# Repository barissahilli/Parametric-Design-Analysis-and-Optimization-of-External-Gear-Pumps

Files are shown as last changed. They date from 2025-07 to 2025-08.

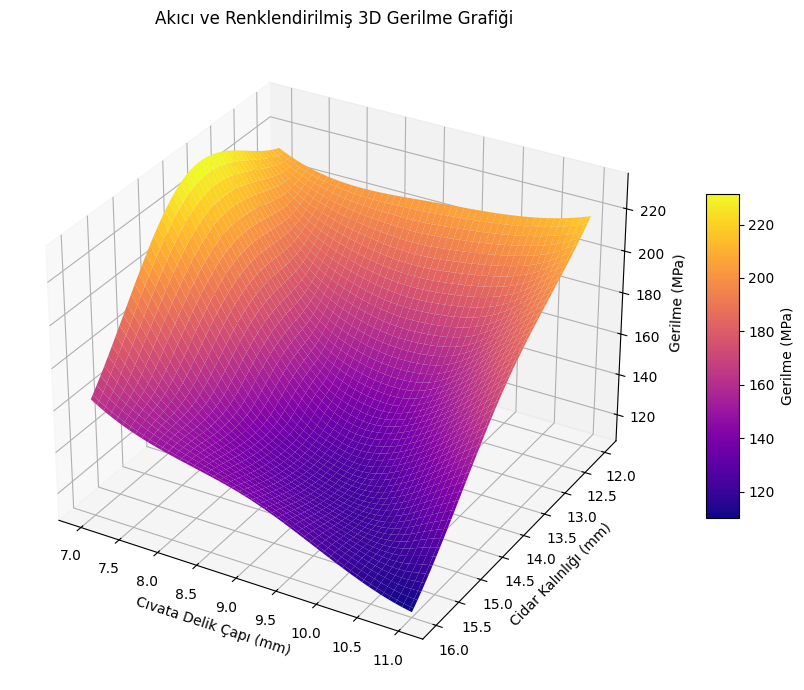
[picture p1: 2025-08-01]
delikcidargerilme.png

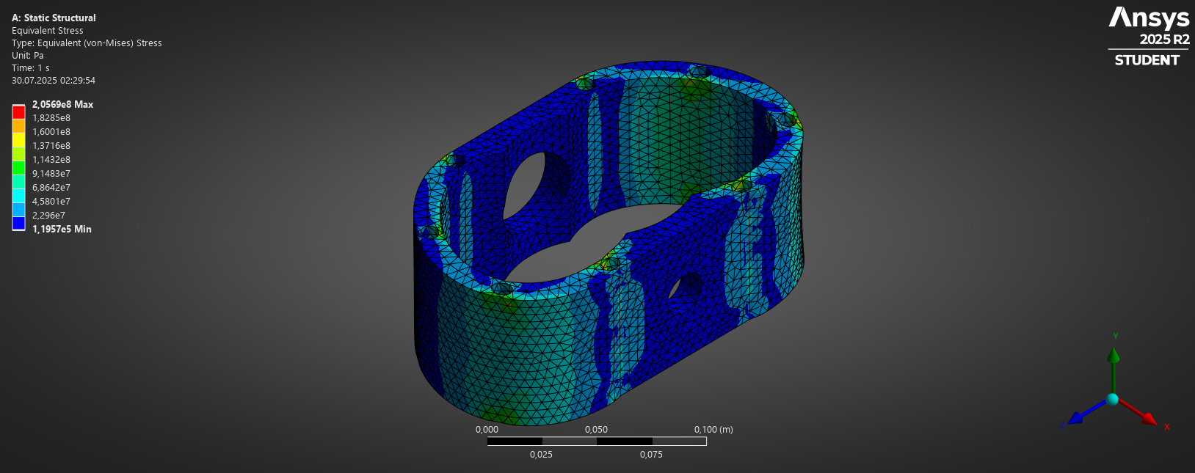
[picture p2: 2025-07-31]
StaticFigure66.png

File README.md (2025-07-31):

# Parametric Design and GDO Analysis of Gear Pump

This project involves the parametric design of a gear pump housing, modeled in SolidWorks and structurally analyzed using ANSYS.

## 📌 Project Overview

- Created 9 different design variations.  
- Analyzed parameters including weight, maximum stress, and maximum displacement.  
- Applied Goal Driven Optimization (GDO) to identify the optimal design.

## 🧪 Tools Used

- SolidWorks (modeling)  
- ANSYS Student (analysis)  
- Excel (DOE table and result analysis)

## 📁 Contents

| File | Description |
|---|---|
| bitirme_raporu.pdf | Detailed project report |
| gdo_grafikleri.png | Stress, weight, and displacement graphs |

## ⚠ Notes

- SolidWorks and ANSYS files are not included. All sections and analysis details are provided in the report.  
- The project was entirely completed using student versions of the software.
- 
> 📄 Note: The final report (bitirme_raporu.pdf) is written in Turkish, as this project was conducted as part of a university graduation requirement in Türkiye.

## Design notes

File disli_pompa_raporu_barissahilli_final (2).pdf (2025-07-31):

T.C.

Dokuz Eylül Üniversitesi

Mühendislik Fakültesi Makine Mühendisliği Bölümü

## DÜZ DİŞLİ POMPANIN PARAMETRİK TASARIMI VE YAPISAL ANALİZİNİN RAPORLANMASI

## HAZIRLAYAN

2021508043 – Barış SAHİLLİ

Temmuz, 2025
İZMİR

## İÇİNDEKİLER

## ÖZET

Bu çalışmada, dişli pompanın parametrik modellemesi SolidWorks yazılımı kullanılarak

yapılmıştır. Oluşturulan model ANSYS Workbench ortamına aktarılmış ve çeşitli analizler

gerçekleştirilmiştir. Yapısal analiz kapsamında von Mises eşdeğer gerilmeler, asal gerilmeler,

deformasyon ve güvenlik katsayıları değerlendirilmiştir. Sonuç olarak, dişli pompa sistemlerinin

dijital ortamda modellenmesi ve simülasyonu ile önceden performans tahmini yapılmasının

önemi ortaya konmuştur.

Anahtar kelimeler: parametrik tasarım, düz dişli pompa, montaj ilişkileri, yapısal analiz.

## 1. GİRİŞ

Dişli pompalar, endüstride sıvı transferinde yaygın olarak kullanılan pozitif deplasmanlı

pompalardır. Bu çalışmada, dişli pompa geometrisinin parametrik olarak modellenmesi ve analiz

edilmesi amaçlanmıştır. Modelleme işlemi SolidWorks yazılımında gerçekleştirilmiş, ardından

analizler ANSYS Workbench ortamında yapılmıştır. Bu sayede tasarımın hem geometrik hem de

yapısal açıdan değerlendirilmesi sağlanmıştır.

## 2. PARAMETRİK MODELLEME (SOLIDWORKS)

SolidWorks yazılımında oluşturulan dişli pompa modeli tamamen parametrik bir yapıda

tasarlanmıştır. Modelde kullanılan tüm ölçüler Global Variables sekmesi ile kontrol

edilebilmektedir. Diş sayısı, modül, merkez mesafesi gibi değişkenler tanımlanarak, bu değerlere

bağlı olarak hem dişli hem de gövde geometrisi otomatik olarak yeniden şekillenmektedir.

Kullanılan başlıca parametrik değişkenler şunlardır:

- Modül (m): Diş yüksekliği, diş profili ve dış çap bu parametreye bağlıdır.
- Diş Sayısı (z): Dişli çapını ve merkez mesafesini belirler. Çap = m × z
- Merkez Mesafesi (a): a = m × z / 2
- Diş Genişliği (b): Dişlinin kalınlığıdır, tork taşıma kapasitesine etki eder.
- Cidar Kalınlığı (t): Gövdeyi saran duvar kalınlığıdır.
- Basma Açısı (alfa): Evolvent diş profili bu açıyla tanımlanır.
- Diş Dibi Çapı (df): df = m * z - 2.5 * m
- Diş Tepesi Çapı (dk): dk = m * z + 2 * m

Montaj sırasında, dişliler eksenel olarak hizalanmış ve uygun hareket kısıtlamaları

tanımlanmıştır. Bu yapı sayesinde, modül ve diş sayısı gibi değişkenlerin değiştirilmesiyle tüm

pompa modeli otomatik olarak güncellenebilmektedir.

## 3. GÖRSEL DETAYLAR VE MONTAJ

Şekil 3.1 – Dişli profiline ait parametrik modelleme detayları

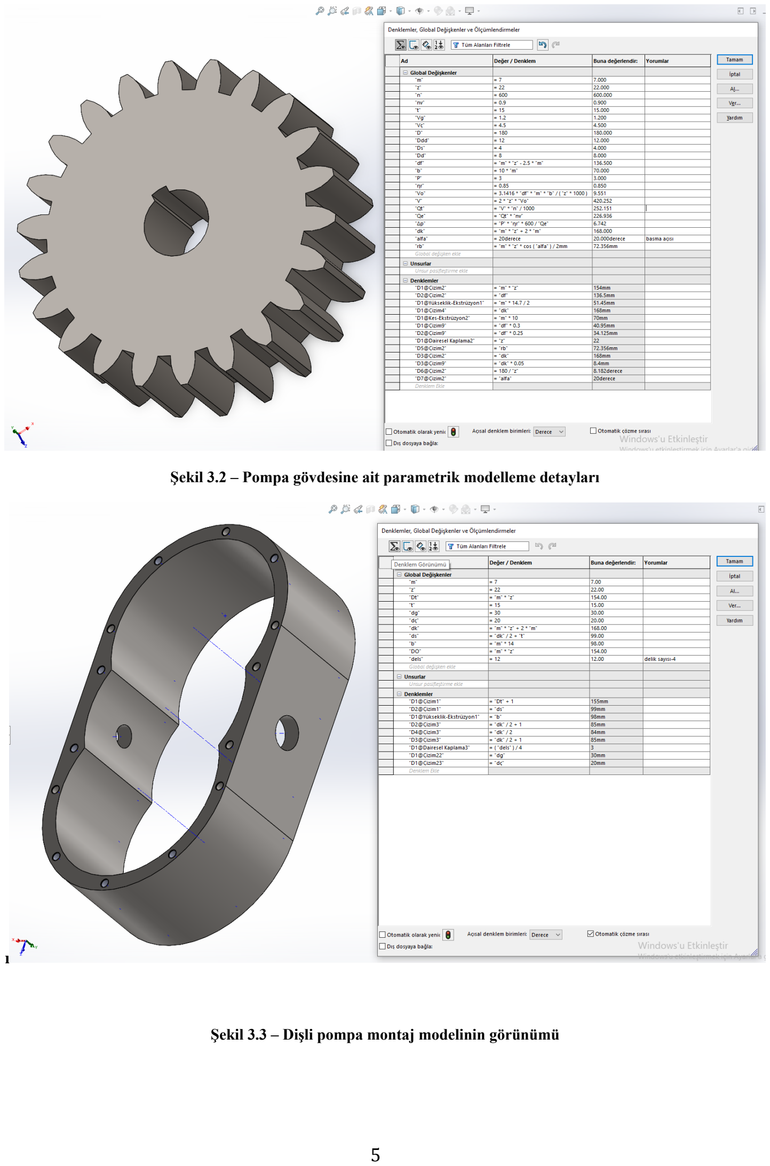
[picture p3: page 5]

Şekil 3.2 – Pompa gövdesine ait parametrik modelleme detayları

ı

Şekil 3.3 – Dişli pompa montaj modelinin görünümü

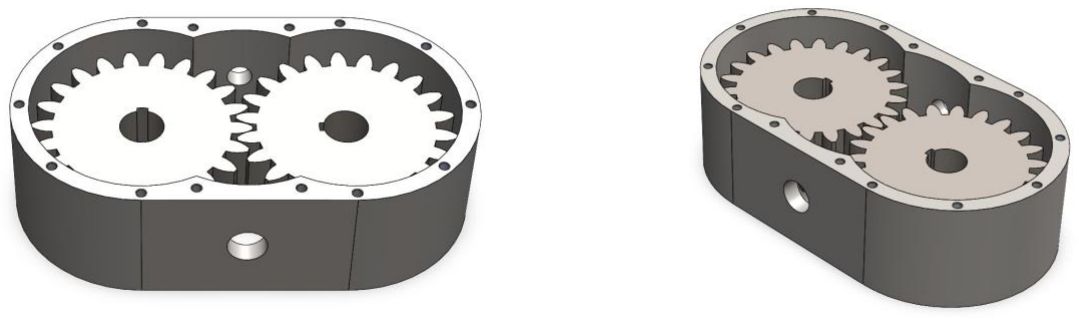
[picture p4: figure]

Şekil 3.4 – Dişli Pompa Çalışma Videosu (QR kod ile izlenebilir)

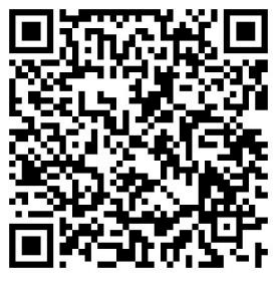
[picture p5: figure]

Alternatif bağlantı: Dişli pompanın çalışma videosunu buraya tıklaayarak izleyebilirsiniz (https://drive.google.com/file/d/1kjITw9gz6Is4c7rqxvNHRtaKOAkZPMQB/view?usp=drive_link)

### 3.1. DIŞLI POMPA MONTAJINDA SOLIDWORKS İLIŞKILERI

Montaj işlemleri sırasında SolidWorks’ün mekanik ilişkiler (mates) sistemi kullanılarak dişli

pompanın parçaları birbirine konumlandırılmış ve doğru hareket ilişkileri tanımlanmıştır.

Aşağıda kullanılan başlıca montaj ilişkileri ve işlevleri açıklanmıştır:

1. Coincident (Çakışık) İlişkisi: Bu ilişki, iki düzlemin veya kenarın aynı hizaya getirilmesini

sağlar.

Kullanım: Pompa gövdesine dişlilerin yataklandığı yüzeylerin hizalanmasında kullanılanılabilir

2. Concentric (Eşmerkezli) İlişkisi: İki silindirik yüzeyin ortak eksen etrafında hizalanmasını

sağlar.

Kullanım: Dişli ile mil, mil ile rulman, rulman ile gövde gibi dönel parçaların aynı eksen

üzerinde düzgün çalışması için uygulanmıştır.

3. Distance (Mesafe) İlişkisi: İki yüzey arasında sabit bir mesafe tanımlar.

Kullanım: Dişli çark ile pompa gövdesi arasındaki boşluk (boşta dönme payı) bu ilişki ile

ayarlanılabilir, montajda aks mesafesi ile ayarlanmıştır.

4. Gear Mate (Dişli İlişkisi): İki dönel parçanın, belirli bir dişli oranına göre senkronize şekilde

dönmesini sağlar, Dişli pompa sisteminde kullanılan ana tahrik dişlisi ile hareketi aktaran dişli

arasında gear mate tanımlanmıştır

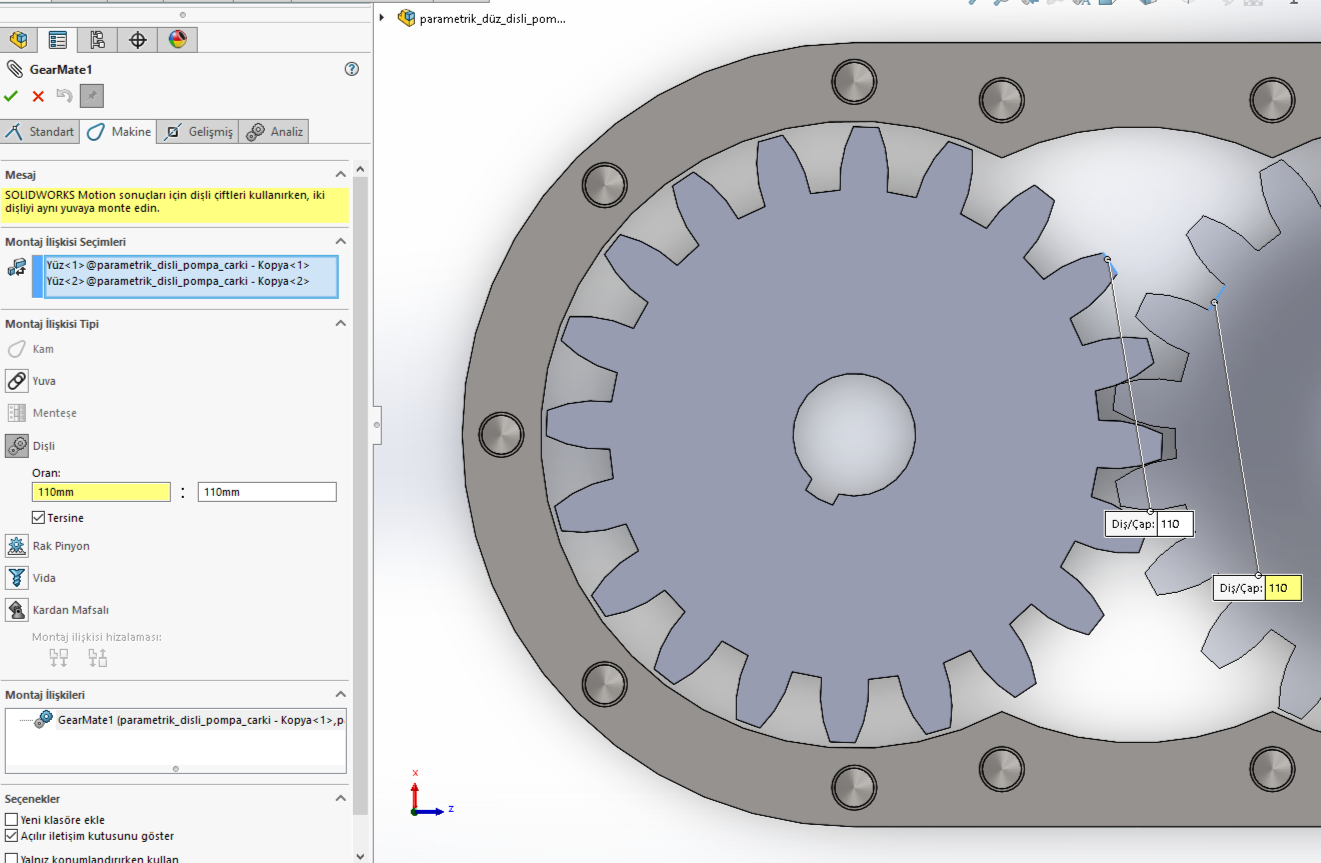
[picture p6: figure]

Şekil 3.5 – Gear Mate İlişkisi Tanımı (SolidWorks)

### 5. Fix (Sabit) İlişkisi Bir parçanın montajda sabit kalmasını sağlar; konumunun değişmesi

engellenir.

Kullanım: Pompa gövdesi montajın referansı olarak sabitlenmiş ve diğer parçalar bu referansa

göre hizalanmıştır.

### 3.2 MALZEME ATAMASI

Bu çalışmada pompa gövdesi ve dişli çarklar için farklı mekanik gereksinimlere uygun olarak

farklı malzemeler seçilmiştir. Pompa gövdesi, genellikle yapısal taşıyıcılığı ön planda olan ve

statik yükler altında çalışan bir bileşen olduğundan, AISI 1020 çelik malzemesi tercih edilmiştir.

AISI 1020 düşük karbonlu bir çelik olup, iyi kaynaklanabilirlik, işlenebilirlik ve maliyet avantajı

sunar. Ayrıca yüzey sertleştirme işlemleriyle dayanımı artırılabilir. Düşük karmaşıklıktaki

geometriler ve dar tolerans gerektirmeyen bölgeler için yeterli mekanik özelliklere sahiptir.

Dişli çarklar ise dönel hareketin ve yüksek temas gerilmelerinin oluştuğu elemanlar olduğundan,

daha yüksek mukavemet, tokluk ve aşınma dayanımı gerektirir. Bu nedenle dişliler için AISI

4130 alaşımlı çelik tercih edilmiştir. AISI 4130, yüksek mukavemetli, ısıl işlemle

sertleştirilebilen bir çeliktir. Bu çalışmada, 870 °C’de tavlanmış hali esas alınarak kullanılmıştır.

Bu ısıl işlem, çeliğin çekme ve akma dayanımını artırırken, malzemenin darbeye karşı dayanıklı

kalmasını sağlar. Böylece dişlilerin sürekli çalışan bir pompa sisteminde güvenli ve uzun ömürlü

performans göstermesi sağlanır.

Malzeme seçimi yapılırken, parçaların yük tipi, hareket durumu, işlenebilirlik, maliyet ve üretim

kolaylığı gibi kriterler dikkate alınmıştır. Seçilen malzemeler, ANSYS ortamında yapılan yapısal

analizlerde de dikkate alınarak modele atanmıştır.

### 3.3 ÇALIŞMA PRENSİBİ

Pozitif deplasmanlı düz dişli pompalar, iki adet birbirine kenetlenmiş düz dişli çarkın dönmesiyle

çalışan hacimsel pompalardır. Pompa çalıştığında, tahrik miline bağlı olan bir dişli çark hareket

eder ve bu hareket diğer çarkı da döndürür. Dişliler dönmeye başladığında, giriş tarafında dişler

arasındaki boşluklar genişler ve bu bölgedeki hacim artışı sayesinde akışkan içeri çekilir.

Akışkan, dişlilerin çevresel hareketi ile gövde iç yüzeyinden çıkış tarafına taşınır. Bu sırada

dişlilerin temasta olduğu orta bölgede sızdırmazlık sağlandığı için sıvı tekrar girişe dönemez.

Dişliler çıkış tarafında birbirine yaklaşırken, aralarındaki hacim azalır ve akışkan sistem dışına

doğru basılır. Bu mekanizma sayesinde pompa, sabit hacimli akışkan transferi sağlar ve yüksek basınç altında verimli çalışabilir. Yapısı gereği, bu tür pompalar düşük debili ama yüksek

basınçlı sistemlerde tercih edilir

Dişli çarkların dönme yönü sayesinde sıvı, emişten çıkışa doğru düzgün bir şekilde yönlendirilir.

Bu pompalarda debi; diş sayısı, modül, diş genişliği, devir sayısı gibi parametrelerle doğrudan

ilişkilidir. Bu nedenle pompalar, istenilen akış şartlarına göre parametrik olarak

boyutlandırılabilir. Bu çalışmada geliştirilen modelde de tasarım değişkenleri SolidWorks

ortamında parametrik hale getirilmiş, böylece farklı senaryolara uygun pompa geometrileri

kolayca elde edilebilir hale gelmiştir.,

Pozitif deplasmanlı pompalar, merkezkaç pompalara kıyasla sabit debi sağladıkları için hidrolik

sistemlerde sıkça tercih edilmektedir

### 3.4 PARAMETRİK MODELİN VERİ GİRİŞLERİ VE HESAPLAMALAR

Bu çalışmada, dişli tip pozitif deplasmanlı bir pompa gövdesinin gerilme analizi ve tasarım

optimizasyonu amacıyla parametrik modelleme yöntemi uygulanmıştır. SolidWorks ortamında

oluşturulan model, Ansys Workbench ile entegre edilerek sonlu elemanlar analizine uygun hale

getirilmiştir. Modellemede 12 adet fiziksel ve geometrik parametre tanımlanmıştır. Bu

parametreler arasında cidar kalınlığı (t), modül (m), diş sayısı (z), devir sayısı (n), volümetrik

verimlilik (ηv), efektif debi (Qe), akışkanın giriş ve çıkış hızları (Vg, Vç), gövde üzerindeki açı

ve delik ölçüleri (D, Dd, Ddd, Ds) gibi tasarımı doğrudan etkileyen değerler yer almaktadır.

Tanımlanan bu parametreler doğrultusunda toplam 7 temel formül kullanılarak çıkış debisi (QT),

teorik debi, pompa çıkış gücü (P), basınç farkı (Δp), giriş/çıkış delik çapları (di, do) gibi çıktılar

hesaplanmıştır. Böylece tasarıma girilen her bir parametre değişikliğinde tüm ilişkili boyutlar ve

performans değerleri otomatik olarak güncellenmekte, hem modelin doğruluğu hem de

analizdeki hassasiyet korunmaktadır. Bu yaklaşım, pompa gövdesinin fiziksel koşullar altında

vereceği tepkilerin daha doğru analiz edilmesini sağladığı gibi, olası tasarım hatalarının önüne geçilmesinde de büyük avantaj sunmaktadır. Örnek modellemede kullanılan veri girişleri ve

hesaplamalar şekil 3.6 ve şekil 3.7 üzerinde gösterilmiştir.

Şekil 3.6

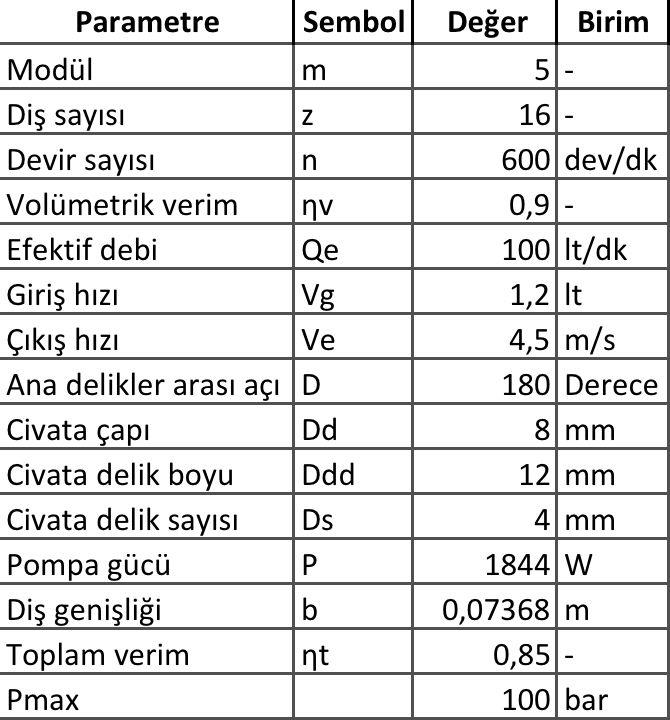
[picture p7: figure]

Bu çalışmada, maksimum çıkış basıncı (Pmax) 100 bar ve toplam verimlilik 0,85 olarak kabul

edilmiştir. Diğer parametreler bu kabuller doğrultusunda düzenlenmiş ve hesaplamalarda

referans alınmıştır.

Basınç farkı (Δp), akışkanın su olduğu varsayımı ile Bernoulli prensibine dayalı olarak, giriş ve

çıkış hızları (Vg ve Vζ) dikkate alınarak hesaplanmıştır. Diş genişliği “b” değeri, birim

dönüşümleri göz önünde bulundurularak milimetre (mm) yerine metre (m) cinsinden girilmiş ve

hesaplamalar buna göre uyarlanmıştır. Pompa çıkış gücü (P), Şekil 3.7’de verilen teorik formüllerden türetilerek elde edilmiş, tüm değerler parametrik modellemede referans alınarak

SolidWorks ortamına entegre edilmiştir.

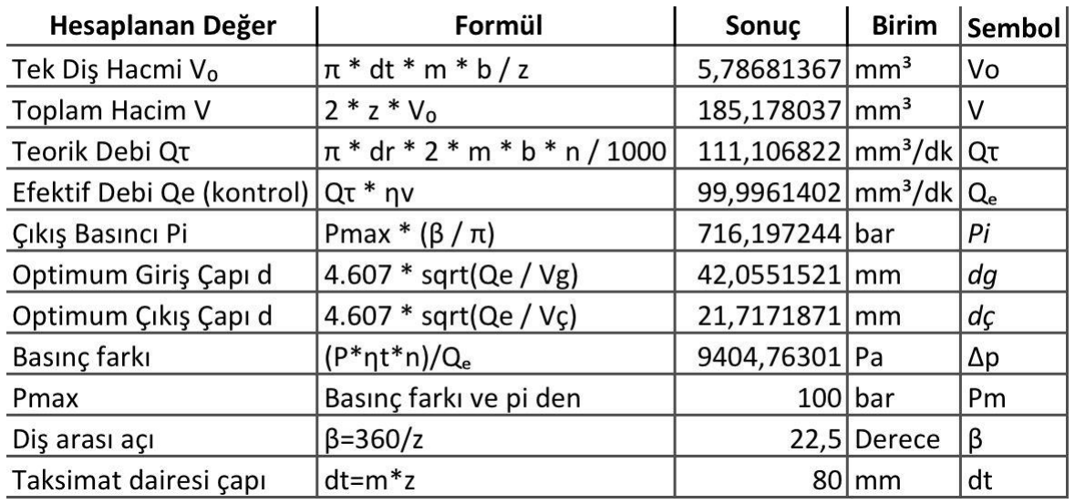
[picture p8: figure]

Şekil 3.7

Şekil 3.7 de görülen hesaplamalar ile ansys static structual analizinde kullanılacak olan işletme

basınç değerlerinin eldesi sağlanmıştır.

## 4. YAPISAL ANALİZ (ANSYS WORKBENCH)

Statik yapısal analiz kapsamında, modelin yük altındaki davranışını değerlendirebilmek için

gerilme türleri detaylı şekilde incelenmiştir. Yapının maruz kaldığı çekme, basma, kayma ve

eğilme gibi yüklemeler sonucunda malzeme içerisinde farklı gerilme türleri oluşur. Bu gerilmeler genel olarak normal gerilme (σ) ve kayma gerilmesi (τ) olarak iki ana grupta toplanır. Yapının

üç boyutlu durumunu değerlendirebilmek için, eşdeğer gerilme (Equivalent Stress) kullanılır.

Bu bağlamda, plastik şekil değiştirme kriteri olan Von Mises gerilmesi, çok eksenli gerilme

durumlarını tek bir değerle temsil eder ve yapının akma sınırına ulaşıp ulaşmadığını belirlemek

için kullanılır. ANSYS içerisinde yapılan analizlerde "Equivalent (Von-Mises) Stress" olarak

gösterilen bu değer, malzemenin dayanımını aşan kritik bölgelerin tespitinde önemli rol oynar.

Von Mises teorisi, malzemenin akma davranışını, enerji esaslı bir yaklaşımla değerlendirir. Bu

çalışmada, dişli pompa bileşenlerine uygulanan tork ve basınç yükleri altında oluşan gerilmeler

incelenmiş, özellikle gövdede oluşan maksimum Von Mises gerilme değerleri değerlendirilerek,

yapının güvenli çalışma sınırları içinde kalıp kalmadığı yorumlanmıştır. Ayrıca oluşan gerilme

dağılımı, geometrik tasarımın kritik bölgelerinin belirlenmesinde yol gösterici olmuştur.

### 4.1 ANSYS ANALİZ AŞAMALARI

- Geometrinin Hazırlanması:
Pompa modeli SolidWorks’te parametrik olarak çizilmiş, STEP (.step) formatında dışa aktarılmıştır.
Aktarılan model ANSYS Workbench içerisine “Geometry” modülü üzerinden Import Geometry seçeneği ile yüklenmiştir.
- Analiz Türünün Seçilmesi:
Workbench ana penceresinde “Static Structural” analiz türü seçilerek analiz ortamı oluşturulmuştur.
- Malzeme Tanımlamaları:
Gövde için AISI 1020 çelik, çark için AISI 430 gibi uygun malzemeler Engineering Data kısmında tanımlanmıştır.
Malzeme özellikleri (Young Modülü, Poisson Oranı, Akma Gerilmesi vb.) gerçek değerlere göre girilmiştir.
- Mesh (Ağ Yapısı) Oluşturulması:
Geometri “Model” modülünde açılarak ağ yapısı (mesh) oluşturulmuştur.
Kritik bölgelerde (çark kökü, giriş/çıkış bağlantıları vb.) hassasiyet artırılarak refinement işlemi yapılmıştır.

Mesh kalitesi görsel ve sayısal olarak kontrol edilmiştir (Element sayısi, Aspect Ratio) Face sizing uygulanılarak element size 0.003m seçilmiş, Sonuç olarak 102736 bağlantı noktası ve 59255 adet eleman oluşturulmuştur.

- | Sınır | koşullarının | tanımlanması:

Parçanın sabitlenmesi gereken bölgeleri giriş ve çıkış portlarının bulundugu gövde

bölgesi olarak belirlenip, Fixed Support uygulanarak yer değiştirme serbestlikleri

| sınırlandırılmıştır.
- Yük yüzeylerinin oluşturulması:

Gövde parçasının içerisinde çalışan dişli çark geometrisine bağlı olarak diş boşlularının

yüksek basınçta oluşturduğu kavitasyon bölgeleri belirlenmiş ve ANSYS yazılımına

entegre çalışan spaceclaim programı ile yüzlere ayrılmıştır.

- | Yüklerin | tanımlanması:

Gerçek çalışma koşulları göz önünde bulundurularak belirlenen yüzlerde oluşan

basınçlar Pi = Pmax*(β/π) bağıntısıyla hesaplanan yükler uygulanmıştır. Burada Pi ilgili

bölge basıncını Pmax maximum basıncı β ise ilgili bölgenin normalle yaptığı açıyı temsil

| etmektedir.
- | Çözüm | işleminin | başlatılması:

Sınır ve yükleme koşulları tanımlandıktan sonra Solve komutu ile sistem çözülmüş ve

| analiz sonuçları elde edilmiştir.
- | Toplam | deformasyonun | incelenmesi:

Parçanın yükler altındaki şekil değişimi Total Deformation sonucu üzerinden

| değerlendirilmiştir.
- | Von | Mises | gerilme | dağılımının | analizi:

Malzemenin akma sınırına göre karşılaştırma yapmak amacıyla Equivalent Stress (Von

Mises) sonucu gözlemlenmiştir.

- | Güvenlik | değerlendirmesi:

Elde edilen maksimum gerilme değeri, malzemenin akma dayanımı ve güvenlik katsayısı

| ele alınarak parçanın güvenli çalışıp çalışmadığı kontrol edilmiştir.

## 5. SONUÇLAR VE DEĞERLENDİRME

Bu çalışmada gerçekleştirilen modelleme ve analiz sonucunda, dişli pompanın yapısal davranışı önceden öngörülmüş ve kritik bölgeler belirlenmiştir. Parametrik tasarım sayesinde farklı senaryolar hızlı şekilde test edilerek, tasarım iyileştirmeleri yapılabilmiştir. Von Mises ve asal gerilme analizleri ile pompa tasarımının güvenilirliği değerlendirilmiş ve dijital ortamda yapılan simülasyonların tasarım sürecine katkısı gösterilmiştir.

### 5.1 YER DEĞİŞTİRME MİKTARI

Yapılan statik yapısal analiz sonucunda, sistemde meydana gelen maksimum yer değiştirme değeri 0.00010515 metre olarak elde edilmiştir. Bu değer, sistemin genel yapısını bozmayacak kadar düşük olup dişlilerin birbirine olan temasını ve çalışma prensibini etkilemeyecek düzeydedir. Bu nedenle, analiz edilen yapı mekanik bütünlüğünü ve işlevselliğini korumaktadır.

Yer değiştirme sonuçları, iki farklı yöntem yardımıyla ifade edilmiştir:

İlki, x0.59 Auto ile abartılı gösterimle elde edilmiştir. Bu, deformasyonun dağılımını daha net gözlemlemek için kullanılmıştır.

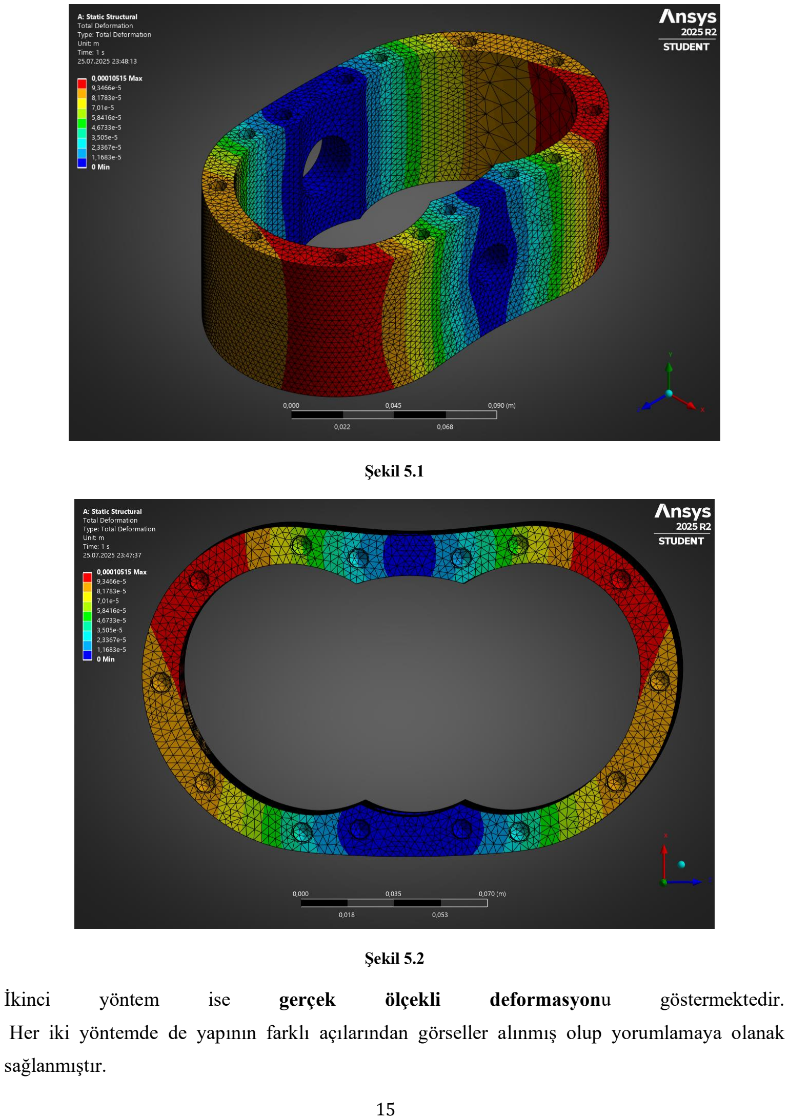
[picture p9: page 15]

Şekil 5.1

Şekil 5.2

İkinci | yöntem | ise | gerçek | ölçekli | deformasyonu | göstermektedir.

Her iki yöntemde de yapının farklı açılarından görseller alınmış olup yorumlamaya olanak

sağlanmıştır.

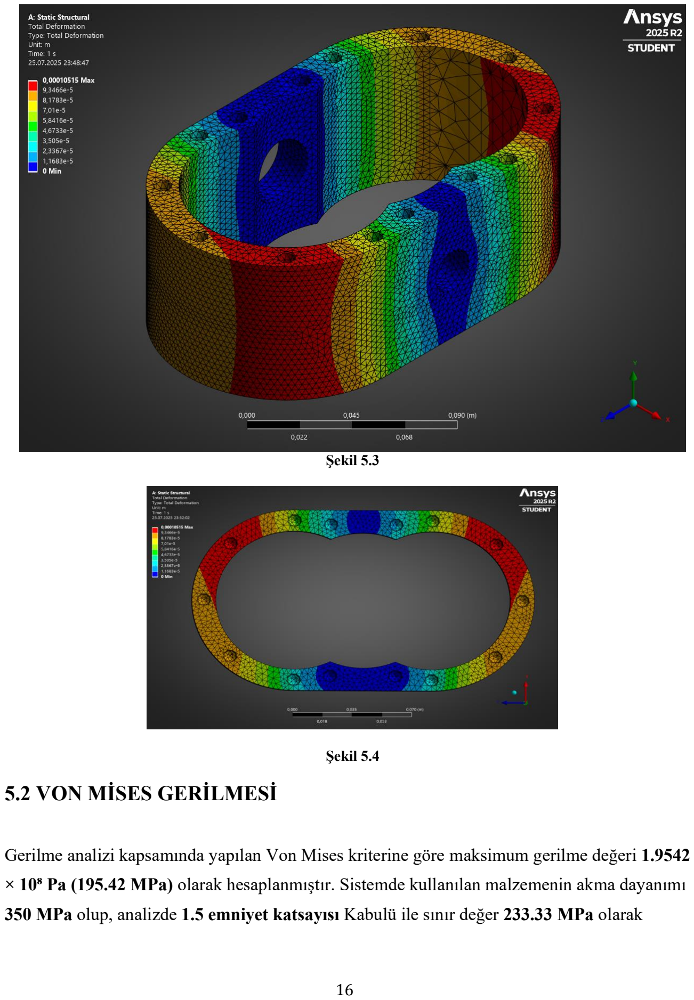
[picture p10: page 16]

Şekil 5.3

Şekil 5.4

### 5.2 VON MİSES GERİLMESİ

Gerilme analizi kapsamında yapılan Von Mises kriterine göre maksimum gerilme değeri 1.9542

× 10⁸ Pa (195.42 MPa) olarak hesaplanmıştır. Sistemde kullanılan malzemenin akma dayanımı

350 MPa olup, analizde 1.5 emniyet katsayısı Kabulü ile sınır değer 233.33 MPa olarak alınmıştır. Elde edilen maksimum gerilme bu sınır değerin altında kaldığı için yapı güvenli

sınırlar içerisinde çalışmaktadır.

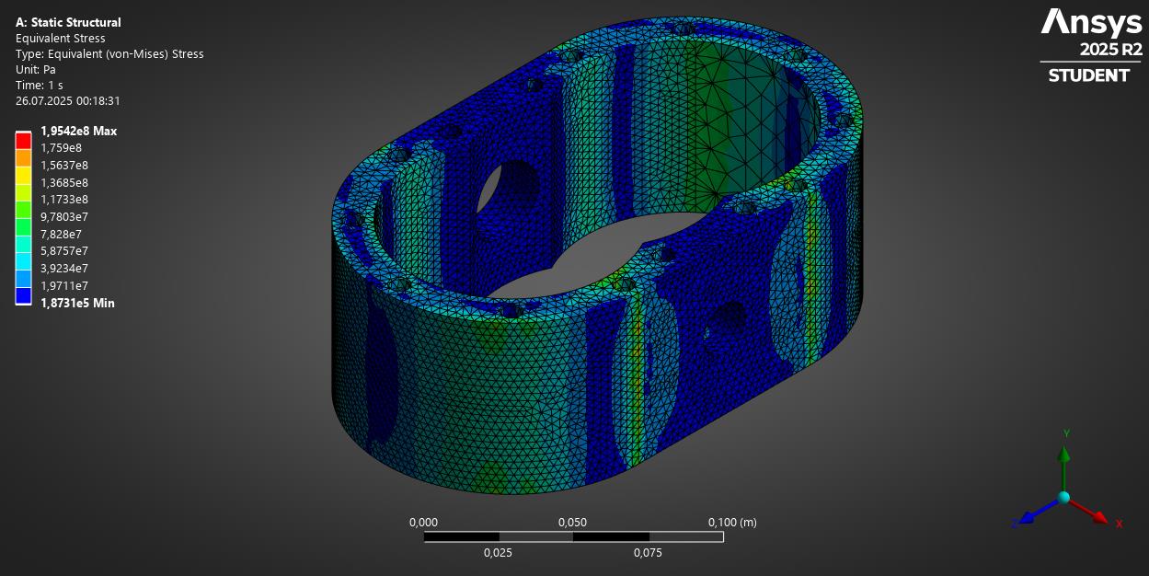
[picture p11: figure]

Şekil 5.5

Bu sonuçlar doğrultusunda, dişli sisteminin hem dayanım hem de deformasyon açısından

güvenilir olduğu ve tasarım kriterlerine uygunluk gösterdiği anlaşılmaktadır.

## 6. OPTİMİZASYON

Bu çalışmada, yüksek basınç altında çalışan dişli pompa gövdesinin yapısal dayanımını artırmak

amacıyla parametrik analizler ve çok değişkenli optimizasyon süreci uygulanmıştır. ANSYS

ortamında yürütülen bu analizlerde, gövde geometrisinde değişiklik yapılan 9 farklı varyant

modellenmiştir. Her bir varyantta; gövde et kalınlığı, flanş yapısı, cıvata bağlantı noktalarının

yerleşimi, dişli yataklama boşlukları gibi yapısal parametreler değiştirilmiş ve bu değişimlerin

maksimum gerilme, yer değiştirme ve güvenlik katsayısı üzerindeki etkileri değerlendirilmiştir.

Elde edilen sonuçlara göre, bazı varyantlar yüksek dayanım sunarken malzeme verimliliğinde

zayıf kalmış, bazıları ise üretilebilirlik açısından avantajlı olmasına rağmen yapısal bütünlük

açısından yetersiz bulunmuştur. Optimizasyon sürecinde bu karşıtlıklar gözetilerek, hem

mekanik performansı yüksek hem de üretim açısından uygulanabilir bir gövde tasarımına

ulaşılmıştır. Bu metodoloji, dişli pompa tasarımlarında sistematik iyileştirme için güçlü bir temel

sunmaktadır.

### 6.1 DENEY PARAMETRELERİNİN BELİRLENMESİ

Optimizasyon sürecinin sağlıklı ilerleyebilmesi için, tasarımı etkileyen çok sayıda parametre

arasından en kritik olanların seçilmesi gerekmektedir. Bu çalışmada, DOE (Design of

Experiments) yönteminin etkinliğini artırmak amacıyla yalnızca tasarımın performansı üzerinde

doğrudan etkili olan giriş (dizayn) değişkenleri ve bunlara karşılık gelen cevap parametreleri

değerlendirmeye alınmıştır. Girdi değişkenleri olarak pompa gövdesinin cidar kalınlığı ve

bağlantı elemanlarına ait delik çapı belirlenmiş; cevap değişkenleri olarak ise maksimum

eşdeğer gerilme, toplam yer değiştirme ve ağırlık seçilmiştir. Bu parametreler, hem mekanik

güvenilirlik hem de üretim maliyeti açısından sistemi doğrudan etkileyen unsurlar olduğundan

optimizasyon sürecine dahil edilmiştir. Yapılan ön analizler, seçilen parametrelerin sistem

davranışı üzerindeki etkisinin belirgin olduğunu göstermiştir. Böylece, gereksiz hesap yükü

oluşturacak ikincil parametreler dışarıda bırakılarak DOE çalışmasının daha hızlı ve anlamlı

sonuçlar üretmesi sağlanmıştır. Belirlenen girdi parametreleri için 9 Farklı deney varyasyonu

oluşturulmuş olup cevap parametrelerine göre optimizasyon sağlanmıştır. Optimizasyon

hedefleri arasına parça ağırlığı total deformasyon ve eşdeğer gerilmenin minimum tutulması

gözetilmiştir.

### 6.2 DENEY VERİLERİNİN RAPORLANMASI

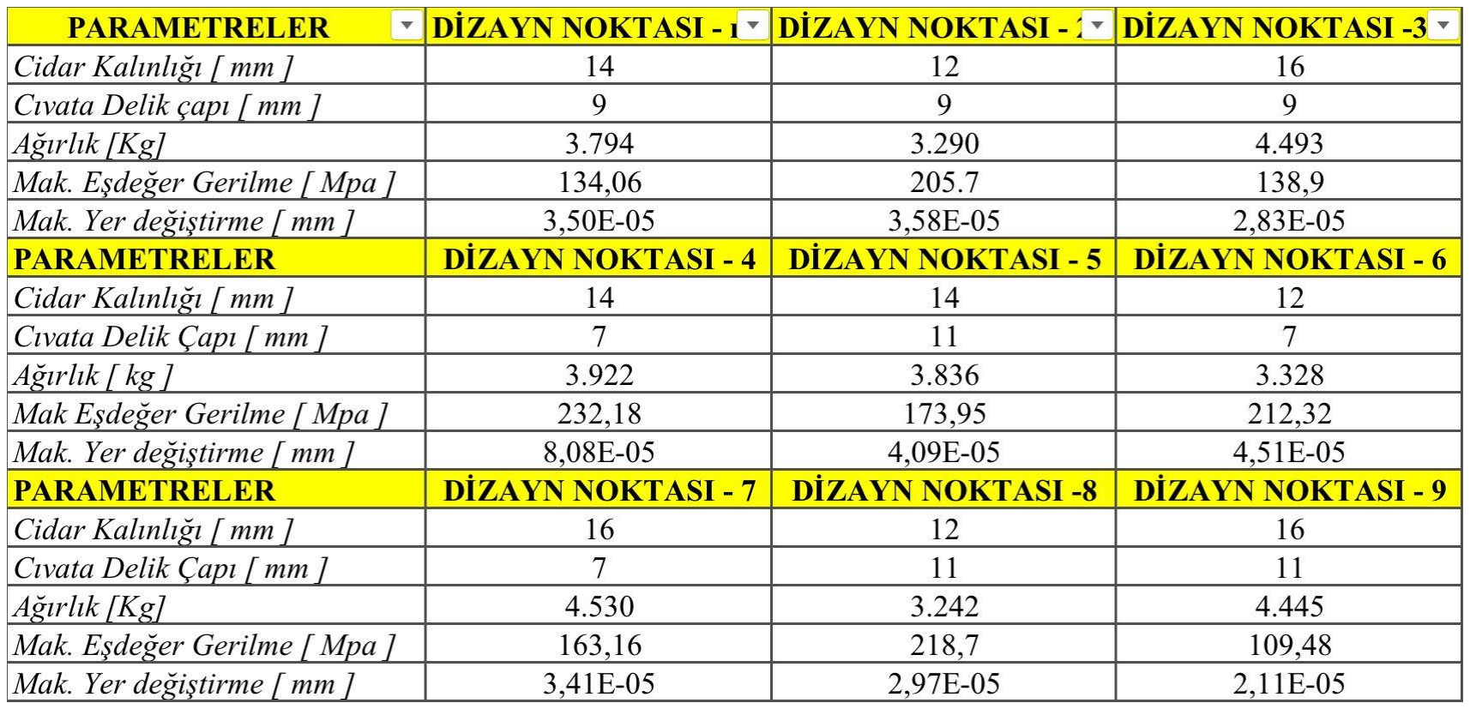
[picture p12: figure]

Şekil 6.1

Yapılan analizlerde elde edilen her varyasyon sonucu değerlendirilmiş; öncelikle malzeme

dayanımına uygunluk ve yapısal stabilite kriterleri göz önünde bulundurulmuştur. Bu kriterleri

sağlayan tasarımlar arasından, en düşük ağırlığa sahip olan model optimum olarak

seçilmiştir.Nihai seçim için kullanılacak karar tablosu özetle şekil 6.2 de gösterilmiştir

Deney | Ağırlık (kg) | Gerilme (MPa) | Yer Değiştirme(mm) | Not
1 | 3.794 | 134.06 | 3,50E-05 | Ağır
2 | 3.290 | 205.70 | 3,57E-05 | Denge iyi
3 | 4.493 | 138.9 | 2,83E-05 | Çok ağır
4 | 3.922 | 232.18 | 8,08E-05 | Gerilme sınırda
5 | 3.836 | 173.95 | 4,09E-05 | Ağır

6 | 3.328 | 212.32 | 4,51E-05 | Yer değiştirme yüksek
7 | 4.530 | 163.16 | 3,41E-05 | Aşırı ağır
8 | 3.242 | 218.7 | 2,97E-05 | GDO: En iyi denge
9 | 4.445 | 109.48 | 2,11E-05 | Çok ağır ama sağlam

Şekil 6.2

Yukarıda Şekil 6.2 farklı cidar kalınlığı ve cıvata deliği çapı kombinasyonları için elde edilen analiz çıktıları özetlenmiştir. DesignXplorer modülünde yapılan amaç odaklı optimizasyon (Goal Driven Optimization - GDO) çalışması kapsamında, minimum ağırlık, minimum eşdeğer gerilme ve minimum yer değiştirme hedeflenmiştir.

Aday tasarımlar arasında yapılan çok kriterli değerlendirme sonucunda, 8 numaralı dizayn, tüm

hedef fonksiyonlar bakımından optimum dengeyi sağlamaktadır. Gerilme değeri 218,7 MPa olup

350 MPa'lık akma sınırına göre (1,5 emniyet katsayısı altında) uygundur. Yer değiştirme ve

ağırlık da diğer tasarımlara göre daha düşük seviyededir buna ek olarak 2 numaralı dizayn da

205,7MPa gerilme değeri ve ağırlık bakımından optimal dengeye yakın konumdadır

Ancak cidar kalınlığı ile delik çapının birbirine yakın olması üretim açısından ve yorulma

ömründe sorun yaratabileceğinden dolayı, 2 numaralı dizayn, teknik sınırlar içinde kalarak daha

güvenli ve dengeli bir çözüm olarak nihai aday olarak seçilmiştir.

## 7. KAYNAKLAR

[1] SolidWorks Yardım Dokümantasyonu
[2] ANSYS Workbench Kullanım Kılavuzu
[3] Makine Mühendisleri Odası Yayınları

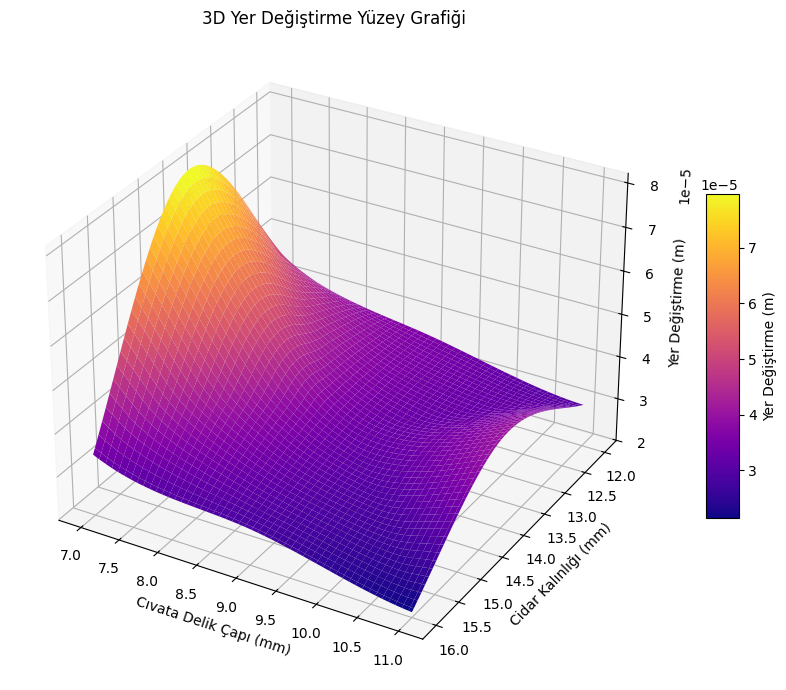
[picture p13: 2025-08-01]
civata delik yerd..png

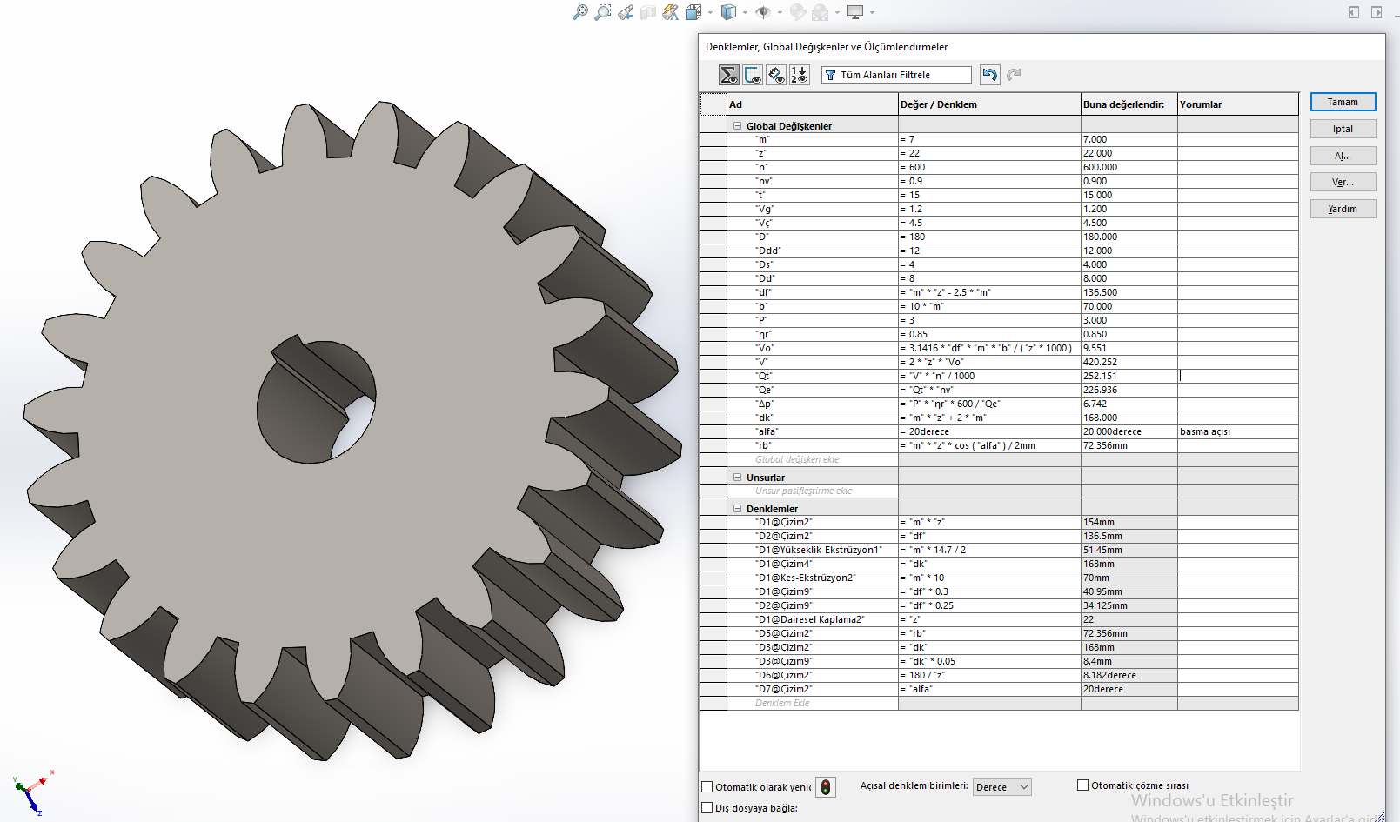
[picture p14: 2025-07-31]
cark-denklemleri.png

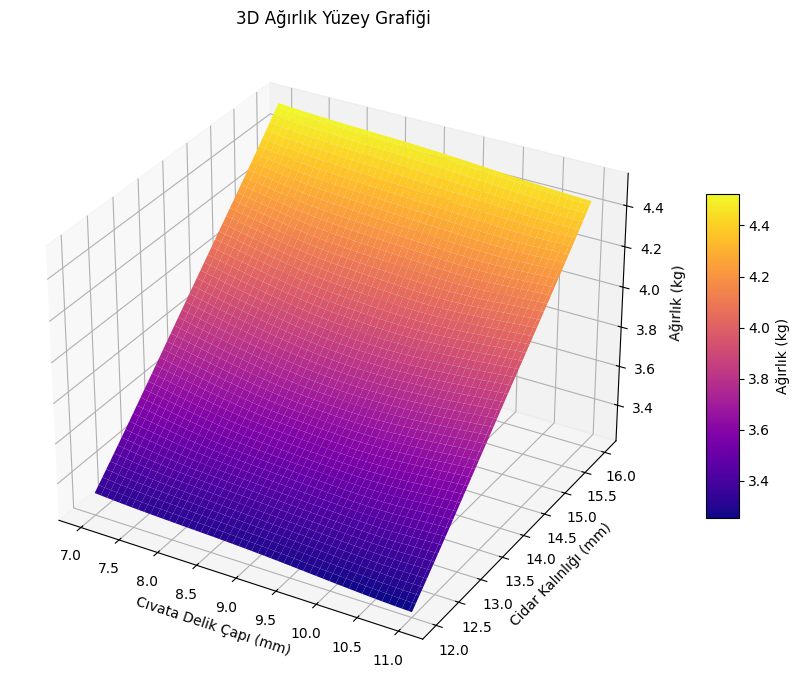
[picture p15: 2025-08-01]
delikcidarağırlık.png

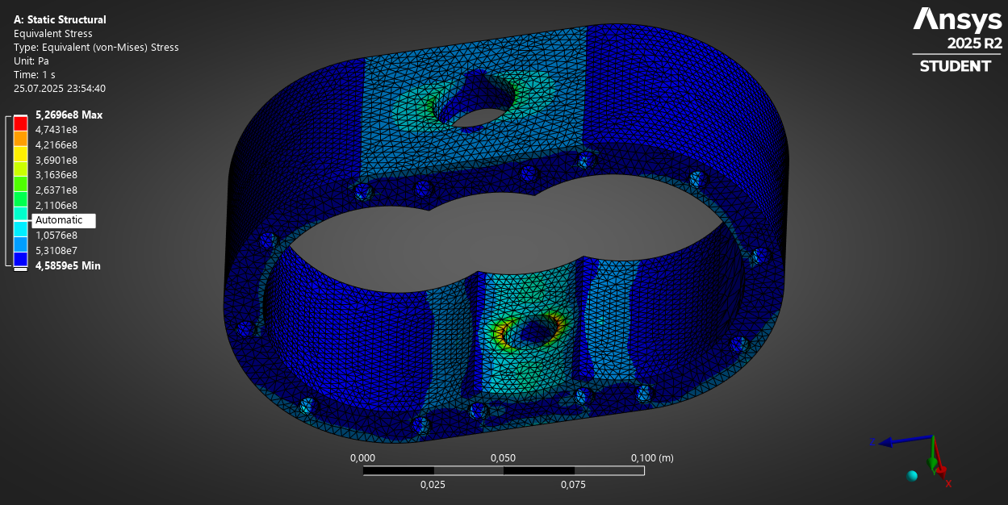
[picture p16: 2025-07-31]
StaticFigure130.png

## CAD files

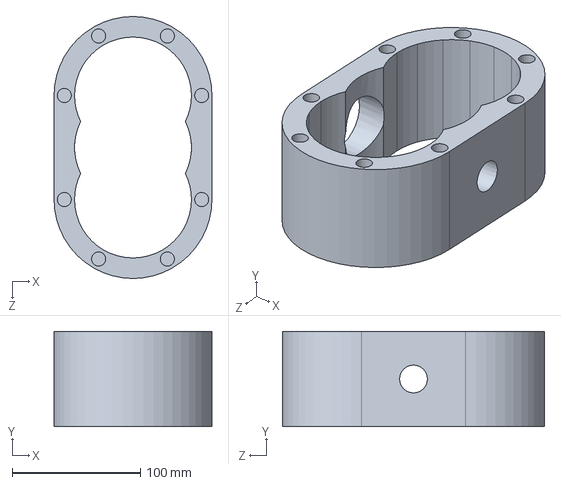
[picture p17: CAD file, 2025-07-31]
pompa_gövde_parametrik.SLDPRT
123.0 x 74.3 x 204.0 mm

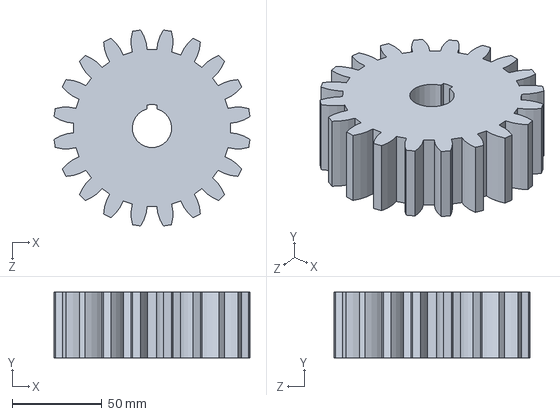
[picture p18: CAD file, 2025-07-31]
parametrik_disli_pompa_carki - Kopya.SLDPRT
109.3 x 36.8 x 109.3 mm
